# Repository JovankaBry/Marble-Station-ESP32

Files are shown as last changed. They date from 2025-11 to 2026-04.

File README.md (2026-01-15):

# Marble-Station-ESP32
This project focuses on the design and implementation of a remote-controlled marble track station with multiple marble containers, based on the ESP32 microcontroller. It includes both the hardware design and software development for wireless control, motor and sensor integration, and communication between modules.

The firmware is developed using PlatformIO with the ESP-IDF framework, ensuring efficient development, debugging, and project management directly in Visual Studio Code.
This setup allows for modular coding, easy dependency handling, and smooth integration with ESP32’s Bluetooth and GPIO features.

Bluetooth-based remote control

# Features
-Automatic marble release (e.g., one marble per second)

-Modular station architecture with multiple containers

-3D-printed mechanical parts for the station setup

## Notes
Konzeption und Implementierung einer fernsteuerbaren Kugelbahn-Stationen mit mehreren Kugelbehältern auf Basis von ESP32 Mikrocontrollern (mit Python oder C). Um Aufgaben aus dem Bereich der Automatisierungstechnik zu bearbeiten, soll für die Lehre eine Kugelbahn realisiert werden (vergleichbar mit z.B. https://www.ravensburger.de/de-DE/produkte/gravitrax). Konkret soll eine Kugelbahnstation aufgebaut werden, die mehrere Kugelbehälter verwaltet. Die Kugelbahnstation soll eine einzelne Kugel aus einem der angeschlossenen Behälter in die Kugelbahn entlassen können. Welche Kugel ausgeworfen wird, soll über Bluetooth gesteuert werden können (der ESP32 bietet hier einfache Funktionen an). Dabei soll auch eine automatische Ausgabe von Kugeln vorgesehen werden (z.B. eine Kugel pro Sekunde). Für den mechanischen Aufbau steht ein 3D-Drucker zur Verfügung. Die Basis ist bereits fertig konstruiert und muss nur um die für diese Aufgabe spezifischen Komponenten erweitert werden.

Die Kugeln sollen auf Schienen entlassen werden. Sie müssen also eine Kugelbahnstation so modifizieren, dass daran Behälter befestigt sind. Ich habe Ihnen in der HTW-Cloud mal die Kugelstation-Basis als shapr3d Datei gespeichert:

Um die Datei zu öffnen, müssen Sie shapr3d auf dem PC oder auf einem iPad installieren und dann die Datei importieren. Das Programm shapr3d ist von Siemens und für Studierende ein Jahr Kostenfrei zu nutzen. Sie müssen sich allerdings registrieren. Beachten Sie, dass die Kugelbahnstation ein Muster ist und von Ihnen angepasst werden muss. Vor allem macht es aktuell keinen Sinn, dass Sie drei Wege haben. Sie müssen den "Schienenkopf" also modifizieren, und zwar so, dass nur noch ein Weg aus der Station heraus führt. Außerdem müssen Sie natürlich die Kugelbehälter ergänzen.

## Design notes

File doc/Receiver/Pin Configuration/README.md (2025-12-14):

# Receiver Pin Configuration

We are using `7 servos` , `1 sensors` , `4 DC Motor`
## Servos
- 3 Servos for ball gate
- 4 Servos for ball door

## DC Motors
- 4 DC Motors for ball lift

## Sensor
- 1 Sensor to control 3 Servos for ball gate and 4 motors for the lift

## Pin Configuration Table
These are the list and the pins for the receiver:

| Component |  GPIO |
|---:|---|
|  Servo 1  | 13 |
|  Servo 2  | 12 |
|  Servo 3  | 14 |
|  Servo 4  | 27 |
|  Servo 5  | 26 |
|  Servo 6  | 25 |
|  Servo 7  | 33 |
|  Motor 1 AIN1 | 16  |
|  Motor 1 AIN2 | 17  |
|  Motor 2 BIN1 | 21  |
|  Motor 2 BIN2 | 22  |
|  Motor 3 AIN1 | 32  |
|  Motor 3 AIN2 | 15  |
|  Motor 4 BIN1 | 19  |
|  Motor 4 BIN2 | 18  |
|  Sensor 1 | 34 |

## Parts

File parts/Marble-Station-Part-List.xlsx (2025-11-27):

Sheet: BOM Receiver
Marble Station with ESP32
No. | Component | Quantity | Description | Source | Price | Status
1 | ESP-32 38Pin CP2102 | 1 | Main controller (Wi-Fi + Bluetooth) | Ali Express | 4.49 € | In stock
2 | Servo SG90 9g | 2 | Servo Motor 180 6x | Ali Express | 7.38 € | In stock
3 | USB-C Cable | 1 | Ali Express USB-C Cable 3m | Ali Express | 1.89 € | In stock
4 | Cable 22 AWG | 1 | Cable 22 AWG | Ali Express | 8.29 € | In stock
5 | Cable 18 AWG | 2 | Cable 18 AWG RED/Black | Ali Express | 4.94 € | In stock
6 | 3D-Printer | 1 | 3D Printer up to 250€ | Kleineinzeigen | 100.00 € | Not ordered | Total
7 | PLA-Filament | 1 | 3D Printer 1kg Filament | - |  | Not ordered
8 | Adapter 5V 10A | 1 | Netzteil Adapter AC 220V DC 5V 10A | https://www.amazon.de/gp/product/B0DM97JMVS/ref=sw_img_1?smid=A6FTR3WNTF6EM&th=1 | 16.99 € | Ordered
9 | Prototype Board | 2 | 9x7 ; 4x6 @ 2.54 | Ali Express | 5.78 € | In stock
10 | PCB Production | 1 | Jack Power PCB 10x | JLCPcb | 7.43 € | Ordered | 284.08 €
11 | PCB Production | 1 | Jack Power PCB 25x | JLCPcb | 9.55 € | In stock
12 | Power Jack Port | 1 | 5,5X2,5 MM DC Power Jack Buchse Stecker DC005 10x | Ali Express | 1.35 € | In stock
13 | El. Capacitors | 1 | 120 Stück Elektrolytkondensator 16 V 25 V 50 V Aluminium | Ali Express | 3.69 € | In stock
14 | El. Capacitors | 1 | 2200uF 16V 10 pcs | Ali Express | 1.94 € | In stock
15 | Cer. Capacitors | 1 | 300 teile/los 50 V 2PF-0,1 UF 30 THT | Ali Express | 1.69 € | In stock
16 | SMD Electrolytic Cap. | 1 | 16V 1000uF 10x10.2 | Ali Express | 1.99 € | In stock
17 | Gravi Tax Marble Run | 1 | Gravi Tax Base | https://www.amazon.de/Ravensburger-Starter-Set-Kugelbahnsystem-Konstruktionsspielzeug-Produktlinien/dp/B0BSXKTRYZ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 | 28.89 € | In stock
18 | Gravi Tax Entension Trax | 1 | Ravensburger GraviTrax Extension Trax 22414 Erweiterung | Amazon | 15.99 € | In stock
19 | Micro DC Motor | 1 | Micro DC Motor 3 V-6 V 8000 U/min 10x | Ali Express | 2.49 € | In stock
20 | DRV883 | 3 | Motor Driver | Ali Express | 3.57 € | In stock
21 | TCRT5000 | 3 | Infrarot Reflektierende Sensor IR 4x | Ali Express | 4.47 € | In stock
22 | Solder Station | 1 | Lötstation Lötset 60W Lötkolben | Amazon | 45.69 € | In stock
23 | Teminal Block | 2 | Terminal Block 3.5mm 2P 50x | Ali Express | 5.58 € | Ordered

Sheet: BOM Transceiver
Marble Station with ESP32
No. | Component | Quantity | Description | Source | Price | Status
1 | ESP-WROOM-32 | 1 | CP2102 WIFI Bluetooth-Modul Dual Core Wireless-Modul ESP-32 ESP-WROOM-32 | Ali Express | 3.79 € | In stock
2 | TFT 1,8 Inch RGB Display | 1 | Vollfarb-TFT-LCD-Anzeigemodul 128 x 160 SPI, ST7735S | Ali Express | 2.30 € | In stock
3 | Tacitile Push Button | 1 | 25PCS Tactile Push Button Switch Momentary 12*12*7,3MM | Ali Express | 1.59 € | In stock
4 | TP4056 | 1 | Charger Module | Ali Express | 2.13 € | Ordered
5 | TP4057 IC | 1 | Charger Module IC 50x | Ali Express | 2.15 € | In stock
6 | BSS84W-7-F | 1 | P Channel MOSFET 50V 50x | Ali Express | 3.89 € | In stock | Total
7 | USB C Female Port | 1 | USB Type C Female Port 10x | Ali Express | 1.29 € | In stock
8 | Battery Terminal Connector | 1 | 2 Pins Terminal Connector | Ali Express | 1.77 € | In stock
9 | Slide Switch | 1 | SK12D07 Kippschalter 3PIN | Ali Express | 2.12 € | In stock
10 | SMD-Diode SOD-123 | 1 | SMD-Diode 0805 SOD-123 S4 1N5819 100x | Ali Express | 2.15 € | In stock | 44.76 €
11 | PCB Production | 1 | Master Screen 5x | JLCPcb | 9.96 € | Ordered
12 | ESP-WROOM-32 | 2 | ESP-32 Bluetooth- und WIFI-Dual-Core-CPU | Ali Express | 1.89 € | Not ordered
13 | EC11 | 1 | EC11 Button + Dreher 5x | Ali Express | 1.94 € | Not ordered
14 | Black Cap EC11 | 1 | Black Cap for EC11 5x | Ali Express | 1.23 € | Not ordered
15 | TFT 3.5 Inch | 2 | 3,5-Zoll-TFT-LCD-Modul mit Touchpanel ILI9488-Treiber 320 x 480 | Ali Express | 6.56 € | Not ordered
16 | Master Prototype V2.00 | 3 | Production for Master Screen V2.00 | JLCPcb | - | Not ordered

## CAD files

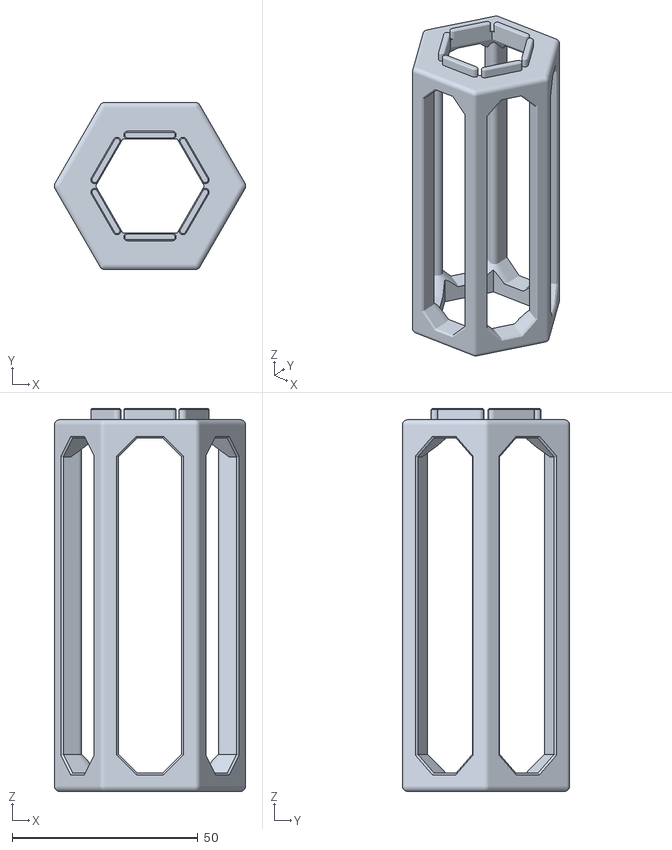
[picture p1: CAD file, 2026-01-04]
cad/GraviTrax/Base/spacer 10 tiles v2.stl
51.5 x 45.0 x 103.0

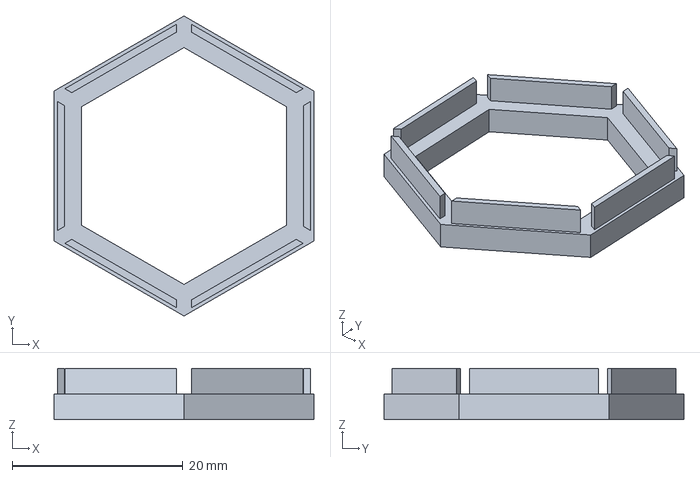
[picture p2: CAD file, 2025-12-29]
cad/GraviTrax/Connector/gravitrax-funnelconnector.3mf
30.4 x 35.1 x 6.00 mm

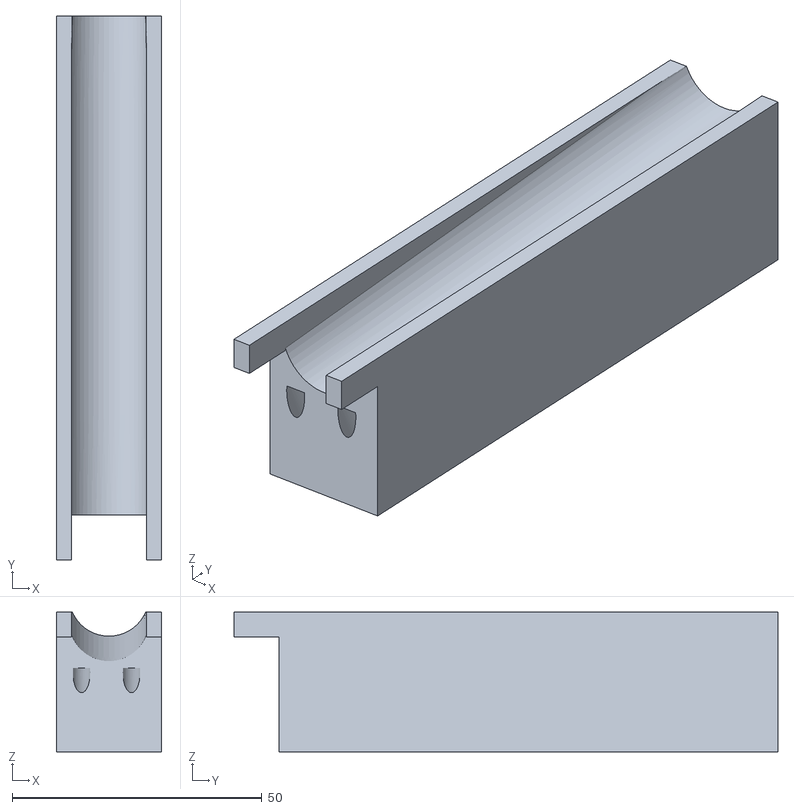
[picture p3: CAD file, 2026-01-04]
cad/main/Ball Container/Door_Container_Servo.stl
21.0 x 109.0 x 28.0

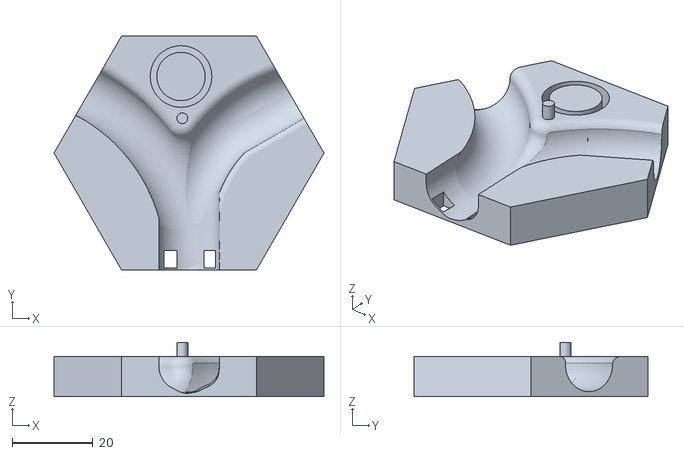
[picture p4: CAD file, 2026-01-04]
cad/main/Base/Base Three Ways.stl
67.0 x 58.0 x 13.5

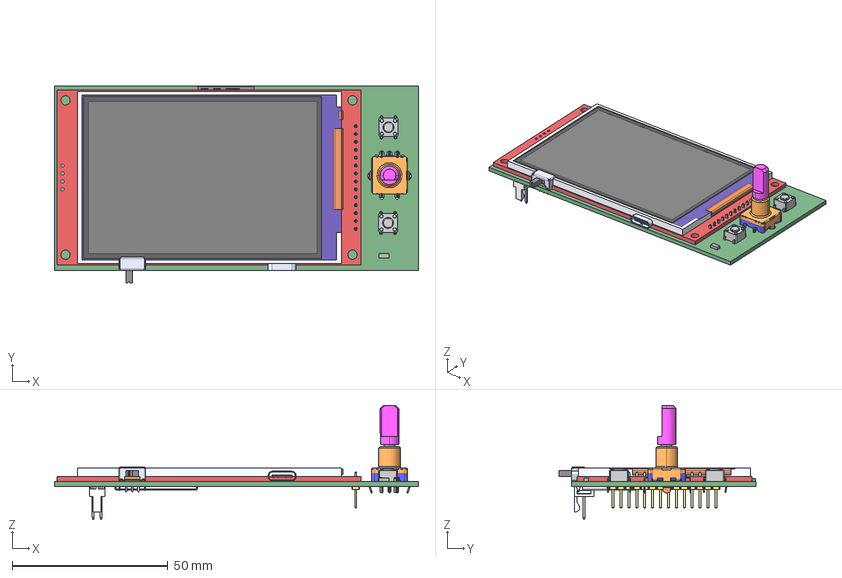
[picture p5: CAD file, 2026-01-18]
cad/PCB/PCB_Master_Screen_V2.01.step
117.0 x 63.2 x 36.8 mm
Button 6x6 x 2
RESC320X160X65L40 x 12
FilletPin1
FilletPin2
chip_0603_r x 6
SW3dPS-0603_SMD_Capacitor x 2
Open_CASCADE_STEP_translator_6.8_8.1.1
Leader x 3
Open_CASCADE_STEP_translator_6.8_8.1.1_1
Leader_1 x 3
прямой_штырь x 16
основание x 16
Display_SPI__3.5_ILI9488
Extruded
USB4105xxx_USB4105GFA060
MP1484EN-LF
22-11-2022_Body_2
22-11-2022_Pins_Tin_5_22-11-2022_Pins_Tin_5 x 2
ec11e15244g1

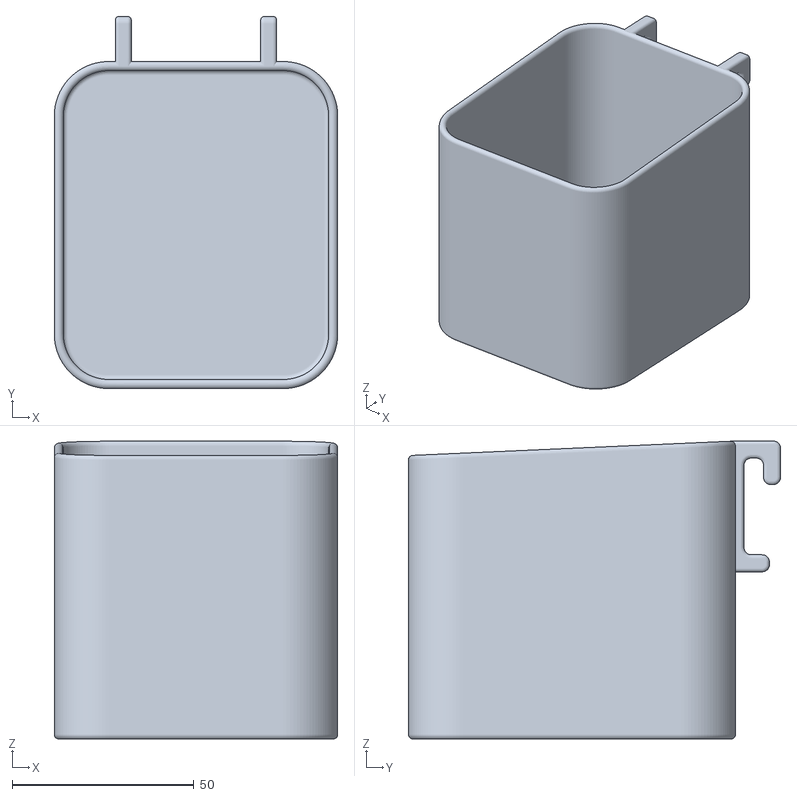
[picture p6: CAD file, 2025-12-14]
cad/Skadis/Small Bin/Bin - Small.stl
78.0 x 102.4 x 82.0

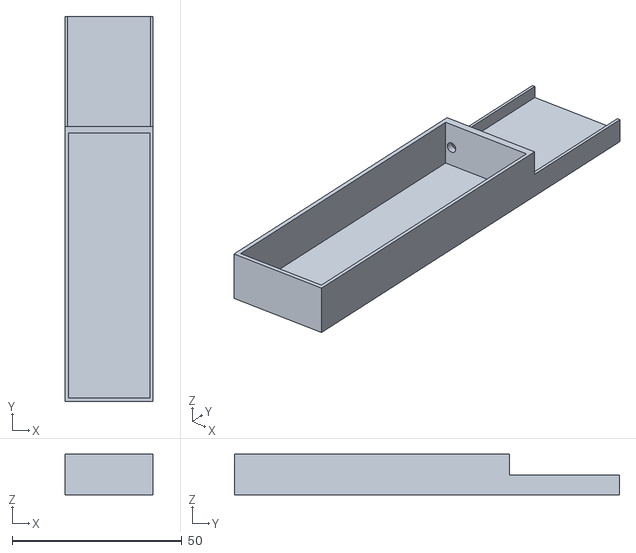
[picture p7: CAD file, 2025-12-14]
cad/TP4056 Case/TP4056 Case.stl
26.0 x 113.5 x 12.0

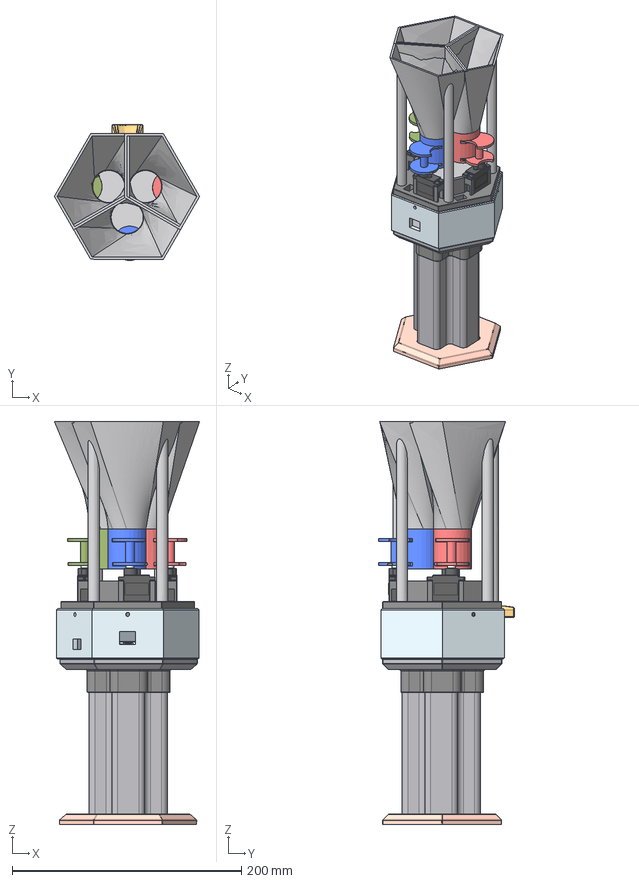
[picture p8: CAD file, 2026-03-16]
shapr/parts/Main Station/V4.00/Marble ESP V4.00.step
126.7 x 118.5 x 351.3 mm
Säule
Green
Red
Blue
ESP32

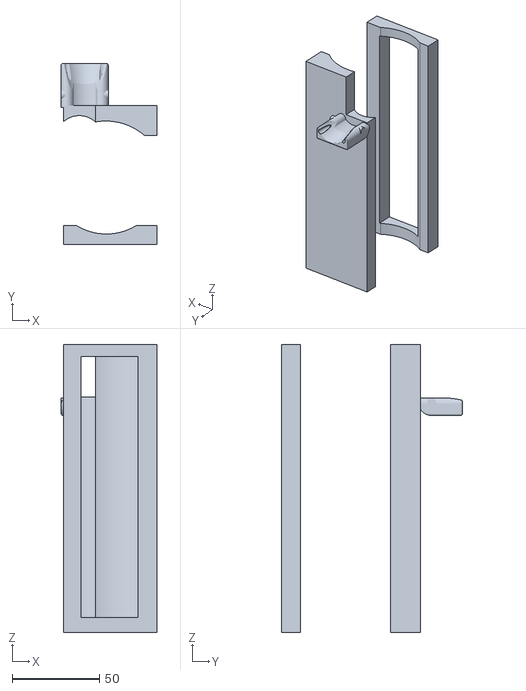
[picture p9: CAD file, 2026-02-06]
shapr/parts/Neben Station/ball lift case/ball lift case V2.00 ext.stl
55.0 x 103.7 x 165.0

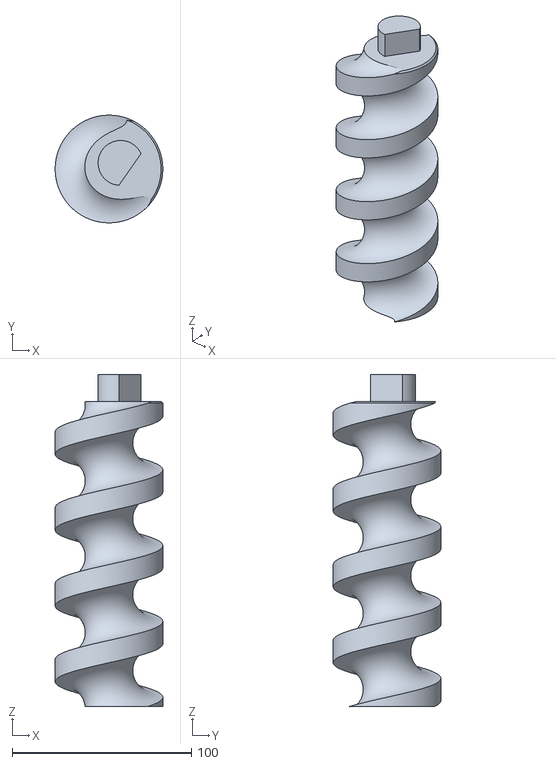
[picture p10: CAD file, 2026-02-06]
shapr/parts/Neben Station/ball lift v1.00/ball lift v2.00 ext.stl
60.0 x 60.0 x 185.0

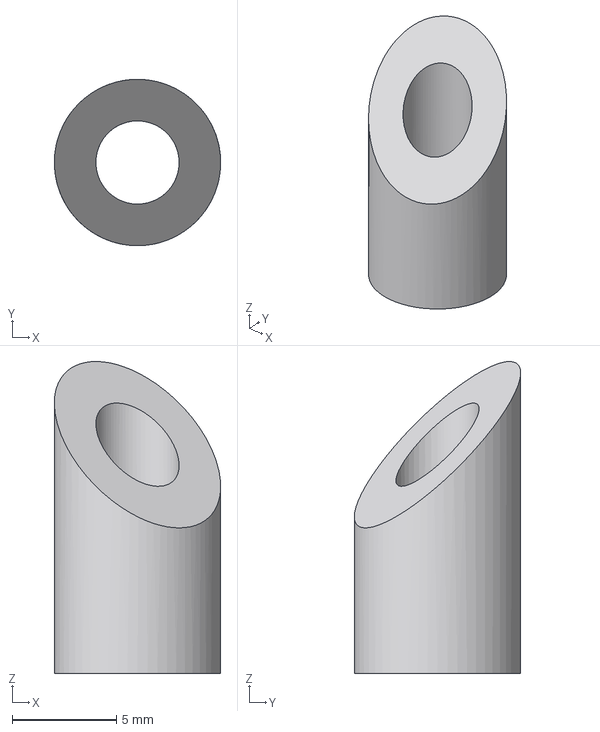
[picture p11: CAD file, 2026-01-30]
shapr/parts/Neben Station/Gewindehalter.step
8.00 x 8.00 x 15.0 mm

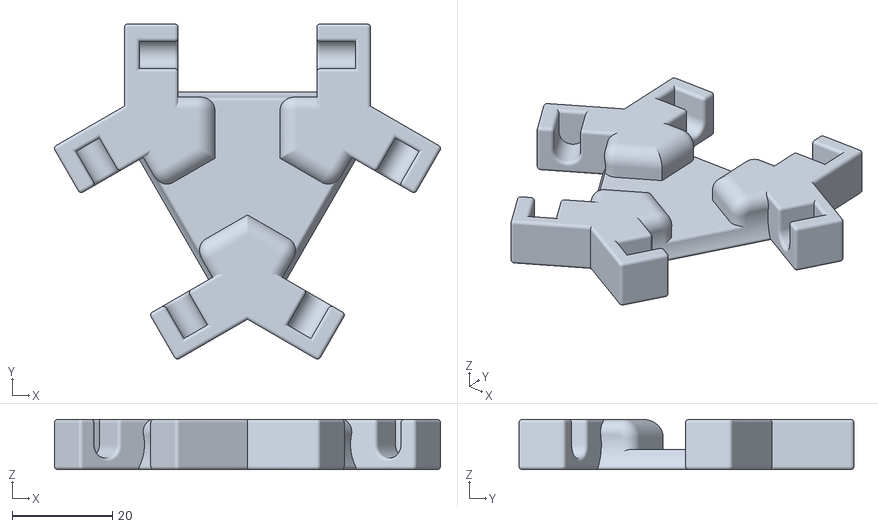
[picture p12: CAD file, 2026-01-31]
shapr/parts/Neben Station/kleinkopf/kleinkof 3 120.stl
76.8 x 66.7 x 10.0

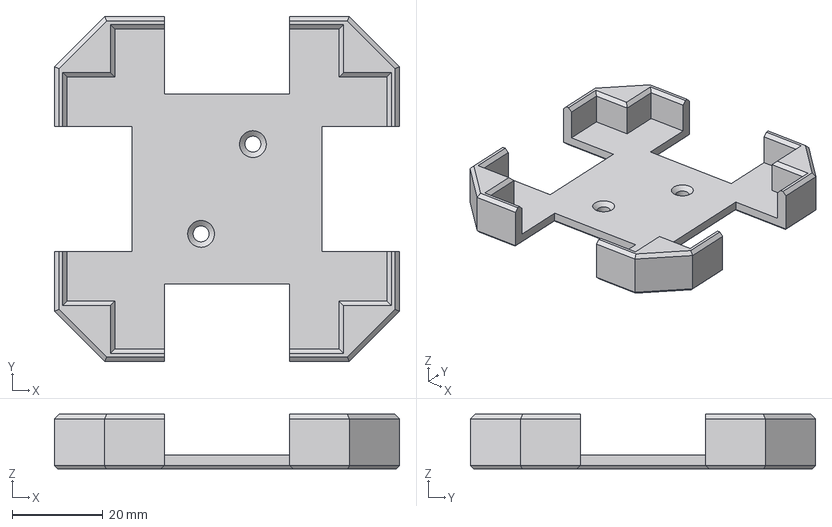
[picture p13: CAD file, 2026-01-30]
shapr/parts/Neben Station/kleinkopfkralle/kleinkopfkralle.step
75.9 x 75.9 x 12.0 mm

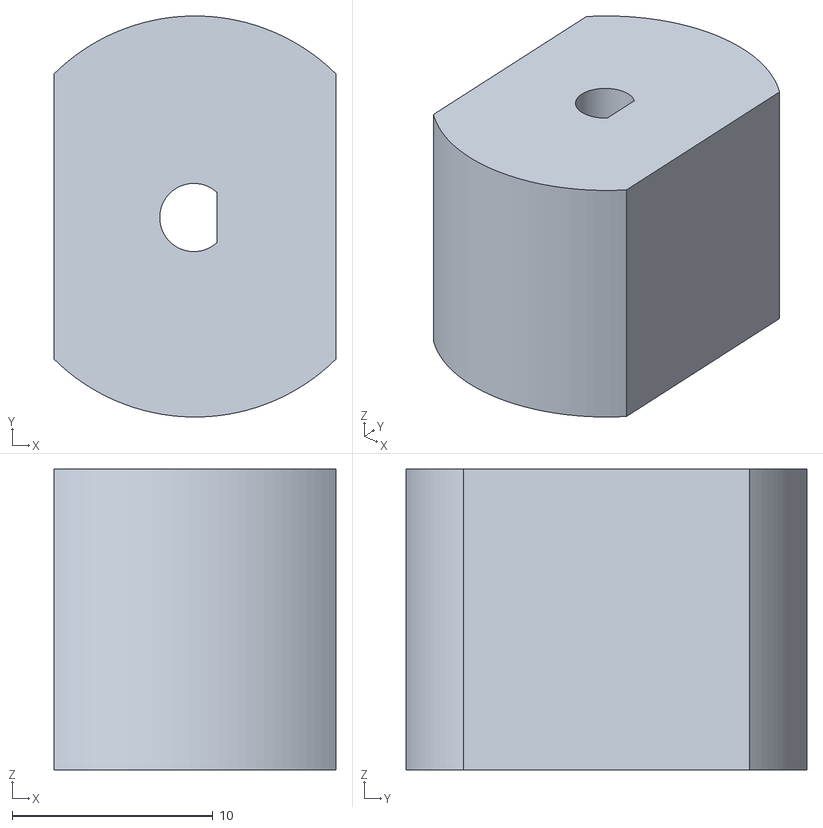
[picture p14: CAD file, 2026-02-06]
shapr/parts/Neben Station/lift rotator/lift rotator.stl
14.0 x 20.0 x 15.0

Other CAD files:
cad/draft/Concept.dwg
cad/Marble 3D Print Template.3mf
shapr/parts/Neben Station/Platform 3/polatform 3.step
shapr/parts/Neben Station/Schieber/achse.step
cad/GraviTrax/Base/Gravitrax_Spacer_10mm_wider_top.stl
cad/GraviTrax/Connector/gravitrax-funnelconnector-v3.step
cad/GraviTrax/Connector/gravitrax-funnelconnector-v3.stl
cad/PCB/PCB_Master_Screen_V2.01 v2.stl
cad/Skadis/Small Bin/M 40 10.stl
cad/TP4056 Case/TP4056 Slicer.3mf
cad/main/Ball Container/Door Base v2.stl
shapr/parts/Main Station/V1.00/1 weg dispenser/1 weg dispenser V1.00.stl
shapr/parts/Main Station/V1.00/1 weg dispenser/Draft/1 weg dispenser V2.00.stl
shapr/parts/Main Station/V1.00/1 weg dispenser/Draft/1 weg dispenser.stl
shapr/parts/Main Station/V1.00/1 weg+spiral/einweg + spiral V1.01.stl
shapr/parts/Main Station/V1.00/1 weg+spiral/einweg + spiral.stl
shapr/parts/Main Station/V1.00/Corpus/Corpus 1 Weg.step
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

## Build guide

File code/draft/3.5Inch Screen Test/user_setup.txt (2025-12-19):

//                            USER DEFINED SETTINGS
//   Set driver type, fonts to be loaded, pins used and SPI control method etc.
//
//   See the User_Setup_Select.h file if you wish to be able to define multiple
//   setups and then easily select which setup file is used by the compiler.
//
//   If this file is edited correctly then all the library example sketches should
//   run without the need to make any more changes for a particular hardware setup!
//   Note that some sketches are designed for a particular TFT pixel width/height

// User defined information reported by "Read_User_Setup" test & diagnostics example
#define USER_SETUP_INFO "User_Setup"

// Define to disable all #warnings in library (can be put in User_Setup_Select.h)
//#define DISABLE_ALL_LIBRARY_WARNINGS

// ##################################################################################
//
// Section 1. Call up the right driver file and any options for it
//
// ##################################################################################

// Define STM32 to invoke optimised processor support (only for STM32)
//#define STM32

// Defining the STM32 board allows the library to optimise the performance
// for UNO compatible "MCUfriend" style shields
//#define NUCLEO_64_TFT
//#define NUCLEO_144_TFT

// STM32 8-bit parallel only:
// If STN32 Port A or B pins 0-7 are used for 8-bit parallel data bus bits 0-7
// then this will improve rendering performance by a factor of ~8x
//#define STM_PORTA_DATA_BUS
//#define STM_PORTB_DATA_BUS

// Tell the library to use parallel mode (otherwise SPI is assumed)
//#define TFT_PARALLEL_8_BIT
//#defined TFT_PARALLEL_16_BIT // **** 16-bit parallel ONLY for RP2040 processor ****

// Display type -  only define if RPi display
//#define RPI_DISPLAY_TYPE // 20MHz maximum SPI

// Only define one driver, the other ones must be commented out
//#define ILI9341_DRIVER       // Generic driver for common displays
//#define ILI9341_2_DRIVER     // Alternative ILI9341 driver, see https://github.com/Bodmer/TFT_eSPI/issues/1172
//#define ST7735_DRIVER      // Define additional parameters below for this display
//#define ILI9163_DRIVER     // Define additional parameters below for this display
//#define S6D02A1_DRIVER
//#define RPI_ILI9486_DRIVER // 20MHz maximum SPI
//#define HX8357D_DRIVER
//#define ILI9481_DRIVER
//#define ILI9486_DRIVER
#define ILI9488_DRIVER     // WARNING: Do not connect ILI9488 display SDO to MISO if other devices share the SPI bus (TFT SDO does NOT tristate when CS is high)
//#define ST7789_DRIVER      // Full configuration option, define additional parameters below for this display
//#define ST7789_2_DRIVER    // Minimal configuration option, define additional parameters below for this display
//#define R61581_DRIVER
//#define RM68140_DRIVER
//#define ST7796_DRIVER
//#define SSD1351_DRIVER
//#define SSD1963_480_DRIVER
//#define SSD1963_800_DRIVER
//#define SSD1963_800ALT_DRIVER
//#define ILI9225_DRIVER
//#define GC9A01_DRIVER

// Some displays support SPI reads via the MISO pin, other displays have a single
// bi-directional SDA pin and the library will try to read this via the MOSI line.
// To use the SDA line for reading data from the TFT uncomment the following line:

// #define TFT_SDA_READ      // This option is for ESP32 ONLY, tested with ST7789 and GC9A01 display only

// For ST7735, ST7789 and ILI9341 ONLY, define the colour order IF the blue and red are swapped on your display
// Try ONE option at a time to find the correct colour order for your display

//  #define TFT_RGB_ORDER TFT_RGB  // Colour order Red-Green-Blue
//  #define TFT_RGB_ORDER TFT_BGR  // Colour order Blue-Green-Red

// For M5Stack ESP32 module with integrated ILI9341 display ONLY, remove // in line below

// #define M5STACK

// For ST7789, ST7735, ILI9163 and GC9A01 ONLY, define the pixel width and height in portrait orientation
// #define TFT_WIDTH  80
// #define TFT_WIDTH  128
// #define TFT_WIDTH  172 // ST7789 172 x 320
// #define TFT_WIDTH  170 // ST7789 170 x 320
// #define TFT_WIDTH  240 // ST7789 240 x 240 and 240 x 320
// #define TFT_HEIGHT 160
// #define TFT_HEIGHT 128
// #define TFT_HEIGHT 240 // ST7789 240 x 240
// #define TFT_HEIGHT 320 // ST7789 240 x 320
// #define TFT_HEIGHT 240 // GC9A01 240 x 240

// For ST7735 ONLY, define the type of display, originally this was based on the
// colour of the tab on the screen protector film but this is not always true, so try
// out the different options below if the screen does not display graphics correctly,
// e.g. colours wrong, mirror images, or stray pixels at the edges.
// Comment out ALL BUT ONE of these options for a ST7735 display driver, save this
// this User_Setup file, then rebuild and upload the sketch to the board again:

// #define ST7735_INITB
// #define ST7735_GREENTAB
// #define ST7735_GREENTAB2
// #define ST7735_GREENTAB3
// #define ST7735_GREENTAB128    // For 128 x 128 display
// #define ST7735_GREENTAB160x80 // For 160 x 80 display (BGR, inverted, 26 offset)
// #define ST7735_ROBOTLCD       // For some RobotLCD Arduino shields (128x160, BGR, https://docs.arduino.cc/retired/getting-started-guides/TFT)
// #define ST7735_REDTAB
// #define ST7735_BLACKTAB
// #define ST7735_REDTAB160x80   // For 160 x 80 display with 24 pixel offset

// If colours are inverted (white shows as black) then uncomment one of the next
// 2 lines try both options, one of the options should correct the inversion.

// #define TFT_INVERSION_ON
// #define TFT_INVERSION_OFF

// ##################################################################################
//
// Section 2. Define the pins that are used to interface with the display here
//
// ##################################################################################

// If a backlight control signal is available then define the TFT_BL pin in Section 2
// below. The backlight will be turned ON when tft.begin() is called, but the library
// needs to know if the LEDs are ON with the pin HIGH or LOW. If the LEDs are to be
// driven with a PWM signal or turned OFF/ON then this must be handled by the user
// sketch. e.g. with digitalWrite(TFT_BL, LOW);

// #define TFT_BL   32            // LED back-light control pin
// #define TFT_BACKLIGHT_ON HIGH  // Level to turn ON back-light (HIGH or LOW)

// We must use hardware SPI, a minimum of 3 GPIO pins is needed.
// Typical setup for ESP8266 NodeMCU ESP-12 is :
//
// Display SDO/MISO  to NodeMCU pin D6 (or leave disconnected if not reading TFT)
// Display LED       to NodeMCU pin VIN (or 5V, see below)
// Display SCK       to NodeMCU pin D5
// Display SDI/MOSI  to NodeMCU pin D7
// Display DC (RS/AO)to NodeMCU pin D3
// Display RESET     to NodeMCU pin D4 (or RST, see below)
// Display CS        to NodeMCU pin D8 (or GND, see below)
// Display GND       to NodeMCU pin GND (0V)
// Display VCC       to NodeMCU 5V or 3.3V
//
// The TFT RESET pin can be connected to the NodeMCU RST pin or 3.3V to free up a control pin
//
// The DC (Data Command) pin may be labelled AO or RS (Register Select)
//
// With some displays such as the ILI9341 the TFT CS pin can be connected to GND if no more
// SPI devices (e.g. an SD Card) are connected, in this case comment out the #define TFT_CS
// line below so it is NOT defined. Other displays such at the ST7735 require the TFT CS pin
// to be toggled during setup, so in these cases the TFT_CS line must be defined and connected.
//
// The NodeMCU D0 pin can be used for RST
//
//
// Note: only some versions of the NodeMCU provide the USB 5V on the VIN pin
// If 5V is not available at a pin you can use 3.3V but backlight brightness
// will be lower.

// ###### EDIT THE PIN NUMBERS IN THE LINES FOLLOWING TO SUIT YOUR ESP8266 SETUP ######

// For NodeMCU - use pin numbers in the form PIN_Dx where Dx is the NodeMCU pin designation
#define TFT_MOSI 23
#define TFT_SCLK 18
#define TFT_CS   5
#define TFT_DC   2
#define TFT_RST  4
#define TFT_BL   -1  // or -1 if tied to 3V3

#define TOUCH_CS 14
#define TOUCH_MOSI 23
#define TOUCH_MISO 19
#define TOUCH_SCLK 18
//#define TOUCH_IRQ 27 
// #define TOUCH_CS 14
//#define TOUCH_IRQ 27   // optional, comment if not connected
  // Reset pin (could connect to NodeMCU RST, see next line)
//#define TFT_RST  -1     // Set TFT_RST to -1 if the display RESET is connected to NodeMCU RST or 3.3V

//#define TFT_BL PIN_D1  // LED back-light (only for ST7789 with backlight control pin)

//#define TOUCH_CS PIN_D2     // Chip select pin (T_CS) of touch screen

//#define TFT_WR PIN_D2       // Write strobe for modified Raspberry Pi TFT only

// ######  FOR ESP8266 OVERLAP MODE EDIT THE PIN NUMBERS IN THE FOLLOWING LINES  ######

// Overlap mode shares the ESP8266 FLASH SPI bus with the TFT so has a performance impact
// but saves pins for other functions. It is best not to connect MISO as some displays
// do not tristate that line when chip select is high!
// Note: Only one SPI device can share the FLASH SPI lines, so a SPI touch controller
// cannot be connected as well to the same SPI signals.
// On NodeMCU 1.0 SD0=MISO, SD1=MOSI, CLK=SCLK to connect to TFT in overlap mode
// On NodeMCU V3  S0 =MISO, S1 =MOSI, S2 =SCLK
// In ESP8266 overlap mode the following must be defined

//#define TFT_SPI_OVERLAP

// In ESP8266 overlap mode the TFT chip select MUST connect to pin D3
//#define TFT_CS   PIN_D3
//#define TFT_DC   PIN_D5  // Data Command control pin
//#define TFT_RST  PIN_D4  // Reset pin (could connect to NodeMCU RST, see next line)
//#define TFT_RST  -1  // Set TFT_RST to -1 if the display RESET is connected to NodeMCU RST or 3.3V

// ###### EDIT THE PIN NUMBERS IN THE LINES FOLLOWING TO SUIT YOUR ESP32 SETUP   ######

// For ESP32 Dev board (only tested with ILI9341 display)
// The hardware SPI can be mapped to any pins

//#define TFT_MISO 19
//#define TFT_MOSI 23
//#define TFT_SCLK 18
//#define TFT_CS   15  // Chip select control pin
//#define TFT_DC    2  // Data Command control pin
//#define TFT_RST   4  // Reset pin (could connect to RST pin)
//#define TFT_RST  -1  // Set TFT_RST to -1 if display RESET is connected to ESP32 board RST

// For ESP32 Dev board (only tested with GC9A01 display)
// The hardware SPI can be mapped to any pins

//#define TFT_MOSI 15 // In some display driver board, it might be written as "SDA" and so on.
//#define TFT_SCLK 14
//#define TFT_CS   5  // Chip select control pin
//#define TFT_DC   27  // Data Command control pin
//#define TFT_RST  33  // Reset pin (could connect to Arduino RESET pin)
//#define TFT_BL   22  // LED back-light

//#define TOUCH_CS 21     // Chip select pin (T_CS) of touch screen

//#define TFT_WR 22    // Write strobe for modified Raspberry Pi TFT only

// For the M5Stack module use these #define lines
//#define TFT_MISO 19
//#define TFT_MOSI 23
//#define TFT_SCLK 18
//#define TFT_CS   14  // Chip select control pin
//#define TFT_DC   27  // Data Command control pin
//#define TFT_RST  33  // Reset pin (could connect to Arduino RESET pin)
//#define TFT_BL   32  // LED back-light (required for M5Stack)

// ######       EDIT THE PINs BELOW TO SUIT YOUR ESP32 PARALLEL TFT SETUP        ######

// The library supports 8-bit parallel TFTs with the ESP32, the pin
// selection below is compatible with ESP32 boards in UNO format.
// Wemos D32 boards need to be modified, see diagram in Tools folder.
// Only ILI9481 and ILI9341 based displays have been tested!

// Parallel bus is only supported for the STM32 and ESP32
// Example below is for ESP32 Parallel interface with UNO displays

// Tell the library to use 8-bit parallel mode (otherwise SPI is assumed)
//#define TFT_PARALLEL_8_BIT

// The ESP32 and TFT the pins used for testing are:
//#define TFT_CS   33  // Chip select control pin (library pulls permanently low
//#define TFT_DC   15  // Data Command control pin - must use a pin in the range 0-31
//#define TFT_RST  32  // Reset pin, toggles on startup

//#define TFT_WR    4  // Write strobe control pin - must use a pin in the range 0-31
//#define TFT_RD    2  // Read strobe control pin

//#define TFT_D0   12  // Must use pins in the range 0-31 for the data bus
//#define TFT_D1   13  // so a single register write sets/clears all bits.
//#define TFT_D2   26  // Pins can be randomly assigned, this does not affect
//#define TFT_D3   25  // TFT screen update performance.
//#define TFT_D4   17
//#define TFT_D5   16
//#define TFT_D6   27
//#define TFT_D7   14

// ######       EDIT THE PINs BELOW TO SUIT YOUR STM32 SPI TFT SETUP        ######

// The TFT can be connected to SPI port 1 or 2
//#define TFT_SPI_PORT 1 // SPI port 1 maximum clock rate is 55MHz
//#define TFT_MOSI PA7
//#define TFT_MISO PA6
//#define TFT_SCLK PA5

//#define TFT_SPI_PORT 2 // SPI port 2 maximum clock rate is 27MHz
//#define TFT_MOSI PB15
//#define TFT_MISO PB14
//#define TFT_SCLK PB13

// Can use Ardiuno pin references, arbitrary allocation, TFT_eSPI controls chip select
//#define TFT_CS   D5 // Chip select control pin to TFT CS
//#define TFT_DC   D6 // Data Command control pin to TFT DC (may be labelled RS = Register Select)
//#define TFT_RST  D7 // Reset pin to TFT RST (or RESET)
// OR alternatively, we can use STM32 port reference names PXnn
//#define TFT_CS   PE11 // Nucleo-F767ZI equivalent of D5
//#define TFT_DC   PE9  // Nucleo-F767ZI equivalent of D6
//#define TFT_RST  PF13 // Nucleo-F767ZI equivalent of D7

//#define TFT_RST  -1   // Set TFT_RST to -1 if the display RESET is connected to processor reset
                        // Use an Arduino pin for initial testing as connecting to processor reset
                        // may not work (pulse too short at power up?)

// ##################################################################################
//
// Section 3. Define the fonts that are to be used here
//
// ##################################################################################

// Comment out the #defines below with // to stop that font being loaded
// The ESP8366 and ESP32 have plenty of memory so commenting out fonts is not
// normally necessary. If all fonts are loaded the extra FLASH space required is
// about 17Kbytes. To save FLASH space only enable the fonts you need!

#define LOAD_GLCD   // Font 1. Original Adafruit 8 pixel font needs ~1820 bytes in FLASH
#define LOAD_FONT2  // Font 2. Small 16 pixel high font, needs ~3534 bytes in FLASH, 96 characters
#define LOAD_FONT4  // Font 4. Medium 26 pixel high font, needs ~5848 bytes in FLASH, 96 characters
#define LOAD_FONT6  // Font 6. Large 48 pixel font, needs ~2666 bytes in FLASH, only characters 1234567890:-.apm
#define LOAD_FONT7  // Font 7. 7 segment 48 pixel font, needs ~2438 bytes in FLASH, only characters 1234567890:-.
#define LOAD_FONT8  // Font 8. Large 75 pixel font needs ~3256 bytes in FLASH, only characters 1234567890:-.
//#define LOAD_FONT8N // Font 8. Alternative to Font 8 above, slightly narrower, so 3 digits fit a 160 pixel TFT
#define LOAD_GFXFF  // FreeFonts. Include access to the 48 Adafruit_GFX free fonts FF1 to FF48 and custom fonts

// Comment out the #define below to stop the SPIFFS filing system and smooth font code being loaded
// this will save ~20kbytes of FLASH
#define SMOOTH_FONT

// ##################################################################################
//
// Section 4. Other options
//
// ##################################################################################

// For RP2040 processor and SPI displays, uncomment the following line to use the PIO interface.
//#define RP2040_PIO_SPI // Leave commented out to use standard RP2040 SPI port interface

// For RP2040 processor and 8 or 16-bit parallel displays:
// The parallel interface write cycle period is derived from a division of the CPU clock
// speed so scales with the processor clock. This means that the divider ratio may need
// to be increased when overclocking. It may also need to be adjusted dependant on the
// display controller type (ILI94341, HX8357C etc.). If RP2040_PIO_CLK_DIV is not defined
// the library will set default values which may not suit your display.
// The display controller data sheet will specify the minimum write cycle period. The
// controllers often work reliably for shorter periods, however if the period is too short
// the display may not initialise or graphics will become corrupted.
// PIO write cycle frequency = (CPU clock/(4 * RP2040_PIO_CLK_DIV))
//#define RP2040_PIO_CLK_DIV 1 // 32ns write cycle at 125MHz CPU clock
//#define RP2040_PIO_CLK_DIV 2 // 64ns write cycle at 125MHz CPU clock
//#define RP2040_PIO_CLK_DIV 3 // 96ns write cycle at 125MHz CPU clock

// For the RP2040 processor define the SPI port channel used (default 0 if undefined)
//#define TFT_SPI_PORT 1 // Set to 0 if SPI0 pins are used, or 1 if spi1 pins used

// For the STM32 processor define the SPI port channel used (default 1 if undefined)
//#define TFT_SPI_PORT 2 // Set to 1 for SPI port 1, or 2 for SPI port 2

// Define the SPI clock frequency, this affects the graphics rendering speed. Too
// fast and the TFT driver will not keep up and display corruption appears.
// With an ILI9341 display 40MHz works OK, 80MHz sometimes fails
// With a ST7735 display more than 27MHz may not work (spurious pixels and lines)
// With an ILI9163 display 27 MHz works OK.

// #define SPI_FREQUENCY   1000000
// #define SPI_FREQUENCY   5000000
// #define SPI_FREQUENCY  10000000
// #define SPI_FREQUENCY  20000000
#define SPI_FREQUENCY  27000000
// #define SPI_FREQUENCY  40000000
// #define SPI_FREQUENCY  55000000 // STM32 SPI1 only (SPI2 maximum is 27MHz)
// #define SPI_FREQUENCY  80000000

// Optional reduced SPI frequency for reading TFT
#define SPI_READ_FREQUENCY  20000000

// The XPT2046 requires a lower SPI clock rate of 2.5MHz so we define that here:
#define SPI_TOUCH_FREQUENCY  2500000

// The ESP32 has 2 free SPI ports i.e. VSPI and HSPI, the VSPI is the default.
// If the VSPI port is in use and pins are not accessible (e.g. TTGO T-Beam)
// then uncomment the following line:
//#define USE_HSPI_PORT

// Comment out the following #define if "SPI Transactions" do not need to be
// supported. When commented out the code size will be smaller and sketches will
// run slightly faster, so leave it commented out unless you need it!

// Transaction support is needed to work with SD library but not needed with TFT_SdFat
// Transaction support is required if other SPI devices are connected.

// Transactions are automatically enabled by the library for an ESP32 (to use HAL mutex)
// so changing it here has no effect

// #define SUPPORT_TRANSACTIONS

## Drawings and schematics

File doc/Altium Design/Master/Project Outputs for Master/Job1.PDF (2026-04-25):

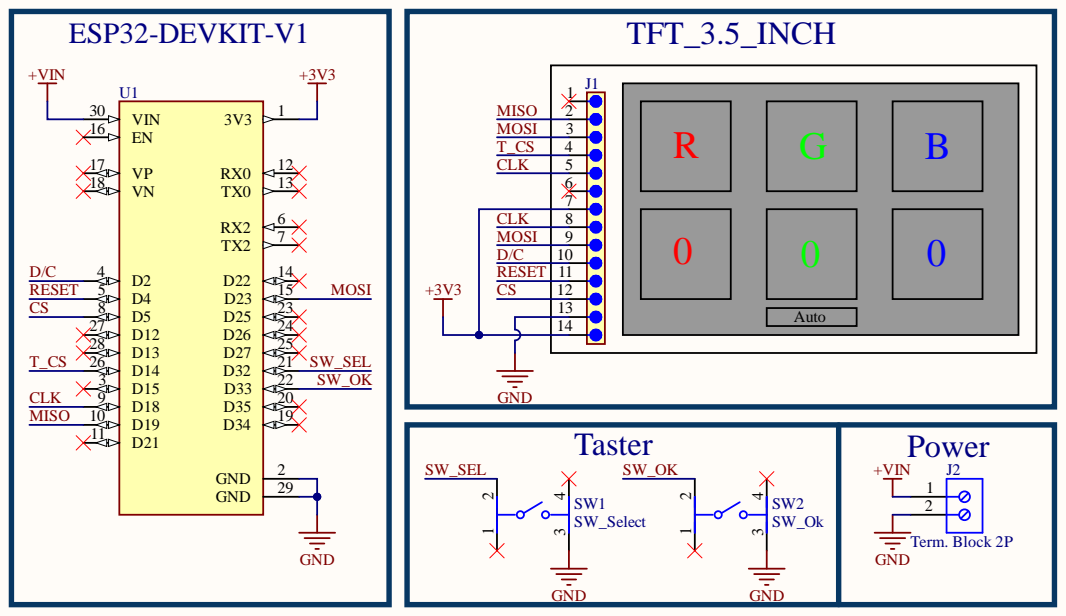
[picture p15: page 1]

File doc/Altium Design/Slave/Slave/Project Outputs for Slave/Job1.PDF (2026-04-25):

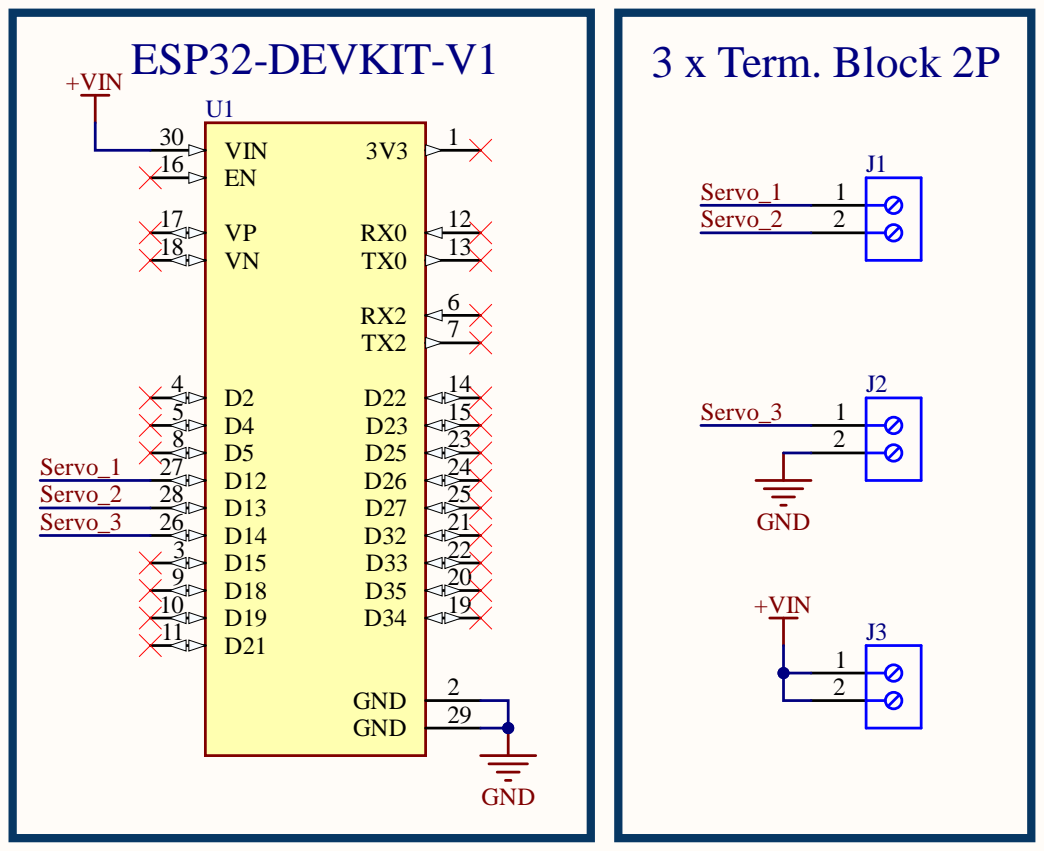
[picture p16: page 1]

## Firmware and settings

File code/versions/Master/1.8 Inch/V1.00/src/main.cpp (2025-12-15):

#include <Arduino.h>
#include <SPI.h>
#include <Adafruit_GFX.h>
#include <Adafruit_ST7735.h>
#include "pages.h"
#include "BluetoothSerial.h"



// Your fixed pins
#define TFT_CS   5
#define TFT_DC   2
#define TFT_RST  4
#define TFT_BL   15  // backlight
#define TFT_MOSI 23
#define TFT_SCLK 18

// Buttons
#define LEFT 19
#define DOWN 14
#define UP   25
#define RIGHT 26
#define OK 27

// Use hardware SPI (MOSI=23, SCLK=18 on ESP32)
//Adafruit_ST7735 tft(TFT_CS, TFT_DC, TFT_RST,TFT_MOSI, TFT_SCLK);

SPIClass vspi(VSPI);
Adafruit_ST7735 tft = Adafruit_ST7735(&vspi, TFT_CS, TFT_DC, TFT_RST);

BluetoothSerial SerialBT;

bool station1selected = true;
int currentPage = 1;

//---------------------------------------Functions----------------------------------------------------------------------------------------
void ReadButtons(){
  if (digitalRead(LEFT) == LOW)  Serial.println("LEFT");
  if (digitalRead(DOWN) == LOW)  Serial.println("DOWN");
  if (digitalRead(UP) == LOW)    Serial.println("UP");
  if (digitalRead(RIGHT) == LOW) Serial.println("RIGHT");
  if (digitalRead(OK) == LOW)    Serial.println("OK");
  delay(50);
}

void updateMenu(){
  if(digitalRead(OK) == LOW && station1selected) Serial.println("to station 2");
  delay(200);
}

//--------------------------------------Setup------------------------------------------------------------------------------------------------
void setup() {
  Serial.begin(115200);

  vspi.begin(TFT_SCLK, -1, TFT_MOSI, TFT_CS);

  pinMode(LEFT, INPUT_PULLUP);
  pinMode(DOWN, INPUT_PULLUP);
  pinMode(UP, INPUT_PULLUP);
  pinMode(RIGHT, INPUT_PULLUP);
  pinMode(OK, INPUT_PULLUP);
  
  pinMode(TFT_BL, OUTPUT);
  digitalWrite(TFT_BL, HIGH);

  // Init display
  tft.initR(INITR_GREENTAB);
  SerialBT.begin("MarbleMaster");
  Serial.println("Bluetooth master starting...");
  drawStation1Page();

}

void loop() {

  //Pressing Right Button
  if (digitalRead(RIGHT) == LOW) {
    if (currentPage == 1) {
      currentPage = 2;
      drawStation2Page();
      Serial.println("to station 2");
    } else if (currentPage == 2) {
      currentPage = 3;
      drawStation3Page();
      Serial.println("to station 3");
    }else if (currentPage == 3){
      currentPage = 4;
      drawStation4Page();
      Serial.println("to station 4");
    }else {
      currentPage = 1;
      drawStation1Page();
      Serial.println("back to station 1");
    }
  SerialBT.write((uint8_t)currentPage);
  SerialBT.flush();
  delay(150); 
  }

  //Pressing Left Button
if (digitalRead(LEFT) == LOW) {
  if (currentPage == 1) {
    currentPage = 4;
    drawStation4Page();
    Serial.println("to station 4");
  }
  else if (currentPage == 4) {
    currentPage = 3;
    drawStation3Page();
    Serial.println("to station 3");
  }
  else if (currentPage == 3) {
    currentPage = 2;
    drawStation2Page();
    Serial.println("to station 2");
  }else{
    currentPage = 1;
    drawStation1Page();
    Serial.println("to station 1");
  }
}
SerialBT.write((uint8_t)currentPage);
SerialBT.flush();
delay(150);
}

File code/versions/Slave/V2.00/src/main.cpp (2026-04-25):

#include <Arduino.h>
#include "servo.h"
#include "bluetooth.h"

void setup() {
    Serial.begin(115200);
    ble_setup();
    setupServo();
}

void loop() {
    char cmd = ble_read();
    if (cmd == 0) return;

    // Debugging received command from Master
    Serial.print("Received command: ");
    Serial.println(cmd);

    // Control servos based on received command
    if (cmd == '1') {
        servo_1();
    } else if (cmd == '2') {
        servo_2();
    } else if (cmd == '3') {
        servo_3();
    }
}

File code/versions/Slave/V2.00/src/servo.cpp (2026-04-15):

#include <Arduino.h>
#include <ESP32Servo.h>
#include "servo.h"

Servo servo1;
Servo servo2;
Servo servo3;

// Servo setup
void setupServo() {
    servo1.attach(12); // Attach the servo to GPIO pin 12
    servo2.attach(13); // Attach the servo to GPIO pin 13
    servo3.attach(14); // Attach the servo to GPIO pin 14

    Serial.println("Servos Ready!");
}

void servo_1(){
    servo1.write(180);
    delay(500);
    servo1.write(90);
    delay(500);
}

void servo_2(){
    servo2.write(140);
    delay(500);
    servo2.write(50);
    delay(500);
}

void servo_3(){
    servo3.write(140);
    delay(500);    
    servo3.write(50);
    delay(500);
}

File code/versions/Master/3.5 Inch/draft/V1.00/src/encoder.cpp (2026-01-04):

#include "encoder.h"
#include "config.h"

static int lastA = HIGH;
static int lastB = HIGH;
static int lastBtn = HIGH;

static uint32_t lastBtnMs = 0;

void encoderInit() {
  pinMode(ENC_A, INPUT_PULLUP);
  pinMode(ENC_B, INPUT_PULLUP);
  pinMode(ENC_BTN, INPUT_PULLUP);

  lastA = digitalRead(ENC_A);
  lastB = digitalRead(ENC_B);
  lastBtn = digitalRead(ENC_BTN);
}

int encoderStep() {
  int a = digitalRead(ENC_A);
  int b = digitalRead(ENC_B);

  int step = 0;

  // same style as your working code: detect change on A
  if (a != lastA) {
    if (a == LOW) {
      if (b == HIGH) step = +1;
      else           step = -1;
    }
    delay(1); // small debounce like your working code
  }

  lastA = a;
  lastB = b;
  return step;
}

bool encoderPressed() {
  int btn = digitalRead(ENC_BTN);

  if (lastBtn == HIGH && btn == LOW) {
    uint32_t now = millis();
    if (now - lastBtnMs > 150) { // debounce
      lastBtnMs = now;
      lastBtn = btn;
      return true;
    }
  }

  lastBtn = btn;
  return false;
}

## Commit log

2025-10-30 Added marble station part list
    [Marble-Station-Part-List.xlsx]
2025-10-31 Added some parts into excel & added cad file for project concept
    [Concept.dwg, Marble-Station-Part-List.xlsx]
2025-10-31 added draft (ESP32 blinking test)
    [Marble-Station-Part-List.xlsx]
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2025-11-02 Added Schematic & PCB for Jack DC
    [PCB_Power_Jack.PcbDoc, Project_Jack_DC.PrjPcb, SCH_Power_Jack.SchDoc]
2025-11-02 Updated needed component
    [Marble-Station-Part-List.xlsx]
2025-11-03 Finished PCB Power Jack
    [Marble-Station-Part-List.xlsx, PCB_Power_Jack.PcbDoc, SCH_Power_Jack.SchDoc]
2025-11-03 Updated the files to the new state
    [Marble-Station-Part-List.xlsx]
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2025-11-09 Improved schematic, and updated excel list
    [Marble-Station-Part-List.xlsx, Prj_Master_Screen.PrjPcb, Sch_Master_Screen.SchDoc]
2025-11-10 Added PCB & Library Database
    [Marble-Station-Part-List.xlsx, PCB_Master_Screen.PcbDoc, Sch_Master_Screen.SchDoc]
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2025-11-11 Deleted Old library, added new library, changed the components using the new library
    [Marble-Station-Part-List.xlsx, Sch_Master_Screen.SchDoc]
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2025-11-12 Added component to pcb
    [PCB_Master_Screen.PcbDoc, Sch_Master_Screen.SchDoc]
2025-11-12 Added TFT-ST7735 TFT LCD
    [PCB_Master_Screen.PcbDoc, Sch_Master_Screen.SchDoc]
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2025-11-12 Finished withmaster screen schematic
    [Marble-Station-Part-List.xlsx, Sch_Master_Screen.SchDoc]
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2025-11-19 Added V1.00 master screen
    [PCB_Master_Screen.GBL, PCB_Master_Screen.GBO, PCB_Master_Screen.GBP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]
2025-11-19 Changed File name to Altium Designer
    [PCB_Master_Screen.GBL, PCB_Master_Screen.GBO, PCB_Master_Screen.GBP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]
2025-11-19 changed file name to V1.00
    [PCB_Power_Jack.GBL, PCB_Power_Jack.GBO, PCB_Power_Jack.GBP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]
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2025-11-26 Changed R's using MarbleLib
    [PCB_Power_Jack_V2.00.PcbDoc, SCH_Power_Jack_V2.00.SchDoc]
2025-11-26 Initial Commit for Layouting
    [PCB_Power_Jack_V2.00.PcbDoc, SCH_Power_Jack_V2.00.SchDoc]
2025-11-26 PCB Power Jack Done, Added Project Output
    [PCB_Power_Jack_V2.00.PcbDoc, Project_Jack_DC_V2.00.PrjPcb]
2025-11-27 Jack Output PCB V2.00 Done
    [PCB_Power_Jack_V2.00.PcbDoc]
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2025-11-27 Added Output Job & Removed stiching via
    [PCB_Power_Jack_V2.00.GBL, PCB_Power_Jack_V2.00.GBO, PCB_Power_Jack_V2.00.GBP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]
2025-12-13 Added TP4056 Case gcode,stl,3mf
    [TP4056 Case.stl, TP4056 Slicer.3mf]
2025-12-13 Updated TP4056 slicer file
    [TP4056 Slicer.3mf]
2025-12-14 added Skadis & updated TP4056 Case V2.00
    [Bin - Small.stl, M 40 10.stl, TP4056 Case.stl]
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2025-12-14 fixed readme receiver pin configuration
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2025-12-19 Added function for EC11
    [PCB_Master_Screen_V2.00.PcbDoc, SCH_Master_Screen_V2.00.SchDoc, V2.00.PrjPcb]
2025-12-20 Added Buck, screen 3.5 to library; -made V2.00 Altium Project
    [PCB_Master_Screen_V2.00.PcbDoc, SCH_Master_Screen_V2.00.SchDoc]
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2025-12-20 Added USB Type C 6p & 16p into library ; continued schematic for master V2.00
    [PCB_Master_Screen_V2.00.PcbDoc, SCH_Master_Screen_V2.00.SchDoc, V2.00.PrjPcb]
2025-12-21 Addded inductor to Lib
    [Prj_Master_Screen_V2.00.PrjPcb, SCH_Master_Screen_V2.00.SchDoc]
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2025-12-28 Initial Commit Master Screen V2.01
    [PCB_Master_Screen_V2.01.PcbDoc, Prj_Master_Screen_V2.01.PrjPcb, SCH_Master_Screen_V2.01.SchDoc]
2025-12-28 Finished Master Screen V2.01
    [PCB_Master_Screen_V2.01.PcbDoc, Prj_Master_Screen_V2.01.PrjPcb, SCH_Master_Screen_V2.01.SchDoc]
2025-12-29 Added Gravitax CAD Files
    [Door Base v2.stl, Gravitrax_Spacer_10mm_wider_top.stl, gravitrax-funnelconnector-v3.step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]
2025-12-30 Added doorbase for servo
    [Base Three Ways.stl, Door Base Servo.stl]
2026-01-04 Added door container stl
    [Door Base Servo.stl, Door_Container_Servo.stl]
2026-01-04 Added V1.00 Master 3.5 Inch
    [Base Three Ways.stl, Gravitrax_Spacer_10mm_wider_top.stl, spacer 10 tiles v2.stl]
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2026-01-18 Added fuss and platform
    [PCB_Master_Screen_V2.01 v2.stl, PCB_Master_Screen_V2.01.step, fuss V2.00.stl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]
2026-01-18 Added 1 Weg schinenbehalter, and spiral for ball way
    [1 Weg.step, spiral ball V1.00.stl, spiral way.stl]
2026-01-19 Added spiral ball v3.00
    [ball 25mm.step, spiral ball V3.00.stl]
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2026-01-22 Added spiral cover and corpus 1 we stl
    [Spiral Cover v1.00.stl, corpus 1 weg.stl, spiral_schienen_v1.00.stl]
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2026-01-24 Added spiral cover v2.00
    [Spiral Cover v2.00.stl, sink_cover_v1.00.step, sink_cover_v1.00.stl]
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2026-01-29 Added Klein lift halter v1.01
    [kkmlift v1.01.stl]
2026-01-29 Added folder for mainstation and neben station
    [1 Weg.step, Corpus 1 Weg.step, Corpus 3 Weg.step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]
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2026-02-02 Added sule short
    [ball lift v1.00.stl, ball lift v2.00.stl, ball lift v3.00.stl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]
2026-02-03 Added Yellow DC Housing
    [Platform.stl, yellow housing.stl]
2026-02-03 Added Code for station1 and station 2
    [ball lift.stl]
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2026-02-06 Added Door dispenser and sevrvo test
    [1 weg dispenser V2.00.stl, 1 weg dispenser.stl, Dispenser + Cover.stl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]
2026-02-06 Added Cover dispenser V2.00
    [Dispenser + Cover V2.00.stl]
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2026-02-24 Working communicating with 2 station
    [ball lift case.stl]
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2026-04-13 changed pin to 33
    [SCH_Master.SchDoc]
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2026-04-25 added fixes
    [SCH_Master.SchDoc, SCH_Slave.SchDoc]
